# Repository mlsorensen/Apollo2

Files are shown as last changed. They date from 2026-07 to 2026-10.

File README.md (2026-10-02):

# Apollo 2

<picture>
  <source media="(prefers-color-scheme: dark)" srcset="docs/img/apollo-logo-dark.png">
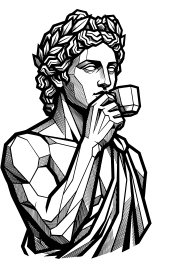
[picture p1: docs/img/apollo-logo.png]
Apollo, laurel-crowned, sipping an espresso
  
</picture>

Firmware project that turns a small ESP32 touchscreen into a local
controller for a **La Marzocco Micra** espresso machine — over Bluetooth, with
no cloud dependency for day‑to‑day use.

Set your brew temperature, flip the steam boiler, put the machine on standby,
watch the boiler come up to temperature, and (with a supported Bluetooth scale)
run a live shot timer and flow graph — all from a dedicated little screen next
to the machine instead of a phone app.

<p align="center">
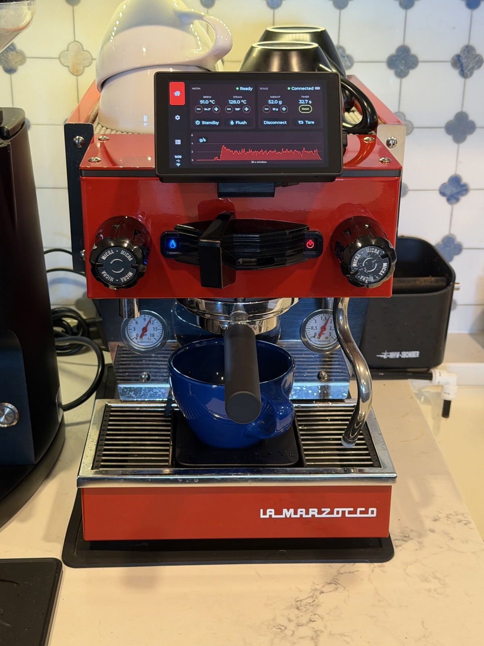
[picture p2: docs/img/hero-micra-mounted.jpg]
Apollo 2 magnet-mounted on a red Micra, Ferrari theme, just after a shot
  
</p>

> The focus is on local control via bluetooth. Currently internet is only used for optional NTP.

**Contents:**
[Features](#features) ·
[Getting started](#getting-started) ·
[Screenshots](#screenshots) ·
[Supported hardware](#supported-hardware) ·
[3D prints](#3d-prints) ·
[Developer documentation](#developer-documentation) ·
[Credits](#credits) ·
[License](#license)

---

## Features

- **Local Micra control over Bluetooth** — brew and steam temperatures, steam
  boiler on/off, standby, and live machine status. No cloud, no phone app.
- **Bluetooth scales** — Bookoo Themis, Acaia (Umbra, Lunar, Prochef, Pyxis)
  and Varia Aku: live weight, shot timer, flow graph, tare, and the scale's
  own settings from the screen.
- **Brew by weight** — stop the shot at a target weight on boards wired into
  the paddle circuit, or detect shots from the weight stream alone on any
  board. Finished shots freeze into a review graph.
- **Group care** — auto‑flush after the cup lifts, flush on demand, and a
  backflush cleaning cycle, on wired boards.
- **Warm‑up chime** — boards with a speaker play a tune when the machine is
  ready, so you can start it and walk away.
- **Schedule** — switch the machine on (with a warm‑up lead) and back to
  standby at set times, the same every day or per weekday, from the device's
  own NTP clock. **Auto‑standby** sends it to standby a set time after the
  last shot, independent of the schedule.
- **Shot history** — every shot is saved to a microSD card as CSV, browsable on
  the device's Stats tab or from a phone via the device's own web page.
- **Settings backup** — preferences copy to the same card and restore onto
  replacement hardware.
- **Over‑the‑air updates** — the device checks for new firmware and installs
  it on request, with an optional beta channel.
- **Setup from your phone, no app** — pairing and Wi‑Fi credentials go in
  through a page the device serves itself; scan the QR code on its screen.
- **Automatic time** — NTP over your Wi‑Fi with a timezone picker, saved to
  the on‑board RTC where present.
- **Made to live on the counter** — themes, °C/°F, 12/24‑hour clock,
  brightness, idle‑screen artwork; layouts from 4.3" to 8" panels.

Everything keeps working if the machine, the scale, or Wi‑Fi is absent — the
UI just shows that part as offline.

---

## Getting started

> [!IMPORTANT]
> **Before buying any hardware, confirm you can get your machine's Bluetooth
> token.** Apollo authenticates to the Micra with a token issued by the La
> Marzocco cloud. Grab it first with the **[LM Token](tools/lmtoken/)** app — sign
> in with your La Marzocco account and copy the token. If it comes back blank, the
> same tool can provision one over Bluetooth. Checking now avoids a nasty surprise
> after a board is already on your bench.

### 1. Get the hardware

Pick a board from the **[Which board?](#which-board)** table below — three of
them come as finished boxes that need no assembly at all. A Bluetooth scale is
optional but unlocks the shot timer, flow graph, and brew‑by‑weight. Wiring
the machine's paddle (for Auto shot) is optional too, and can always be added
later — see the [wiring guide](docs/WIRING.md) (which also covers the
optional Apollo Link board — **P4 boards only**, not the S3‑4.3C).

### 2. Flash the firmware

**No-toolchain option:** the [web flasher](https://mlsorensen.github.io/Apollo2/)
flashes any supported board straight from Chrome, Edge, or Firefox over USB —
pick your board, click Install. (The P4‑5 and P4‑4.3 exist with two ESP32‑P4
chip revisions that need different images; boards bought before about August
2026 are v1.x, newer ones v3. **Detect board** reads it off a device already
running Apollo; on a blank board pick it on the card. A wrong pick just won't
boot until the other image is flashed.) Upgrading this way keeps your paired machine,
Wi‑Fi and settings (unless you choose "Erase device"). Prebuilt images also live
on the [Releases](https://github.com/mlsorensen/Apollo2/releases) page — those
are full images, so flashing one with `esptool` *does* clear saved settings.

Until a Micra is paired, the device opens on a welcome screen with the three
recommended steps: **Set up WiFi** (network and time zone from your phone;
sets the clock and enables updates), **Pair Micra**, and **Pair scale**. All
are optional — **Later** skips it until the next power‑up, **Don't show
again** for good; every step is in Settings too.

After the first flash Apollo updates itself over WiFi: it checks for new
firmware, shows what changed, and installs on a tap. Tick **Include
pre-releases** on the flasher (or turn on **Settings → Apollo → WiFi → Beta
updates** on the device) to run beta builds instead — testing welcome, and a
build that won't boot rolls back on its own.

Building from source requires [PlatformIO](https://platformio.org/) (`pio`) and
a USB cable.

```sh
make flash            # print selection of flash options
make flash-p4-5       # or target a board: p4-5 | p4-4-3 | s3-4-3c | p4-x-8
                      # (P4-5 / P4-4.3 come with two chip revisions needing different
                      #  images; these targets read the chip and pick the right one)
make monitor          # open the serial console (115200 baud)
```

### 3. Pair the machine

**Settings → Micra → Bluetooth → Scan**, then pick your machine. The device saves
it, then asks for the machine's **Bluetooth token** (step 4) — the token is issued
by the La Marzocco cloud and can't be read off the machine, so there's a short
one‑time step to fetch it.

### 4. Enter your token

Tap **Enter token** on the prompt (or **Settings → Micra → Set up**) to start the
device's own Wi‑Fi access point, **`Micra-Setup`**. Scan the QR code on the
device's screen with your phone's camera — it joins the access point and the
setup page pops up on its own. (Or join `Micra-Setup` manually and open
**http://192.168.4.1**.) Paste your token and Save — the device connects and the
access point closes on its own.

Where to get the token:

- Download the **LM Token** app for your OS from the [Releases](../../releases)
  page, unzip, and double-click it. Sign in with your La Marzocco account, pick
  your machine, and hit **Copy token**. This is the only step that uses the
  internet, and it runs on your computer. (Prefer a terminal? The `lmtoken` CLI
  is on the same page.)

> Prefer to build **LM Token** / `lmtoken` from source (Go), or script it? See
> [`tools/lmtoken/README.md`](tools/lmtoken/README.md).

### 5. (Optional) Wi‑Fi + automatic time

On the same setup page you can enter your home Wi‑Fi name and password. The
device then joins your network, gets an IP, and syncs the clock over NTP. Pick
your city under **Settings → Apollo → WiFi → Timezone**. Auto‑sync can be turned
off there too (**Auto time (NTP)**).

Because the setup page is always reachable from **Set up WiFi**, you can never be
locked out if your network changes.

### 6. Find your way around

- **Home** shows the machine (and scale, if paired). The large action button is
  Standby / Turn On when connected, and becomes a **Connect** button when the
  machine is disconnected. With a scale, the pill under the shot timer cycles
  the shot mode — **Auto shot** (wired paddle boards) / **Shot detect** /
  **Manual** — and becomes **Reset** while a finished shot is up for review.
- **Settings** groups everything under Micra, Scale, and Device (brightness,
  clock, units, theme, Wi‑Fi).
- **Stats** shows brew/boiler temperature history, the shot **History** log
  (SD‑card boards), and device info.

Every screen and setting is described in the **[user manual](MANUAL.md)** —
it opens with a **map of every screen and setting** if you're looking for
where something lives.

---

## Screenshots

<p align="center">
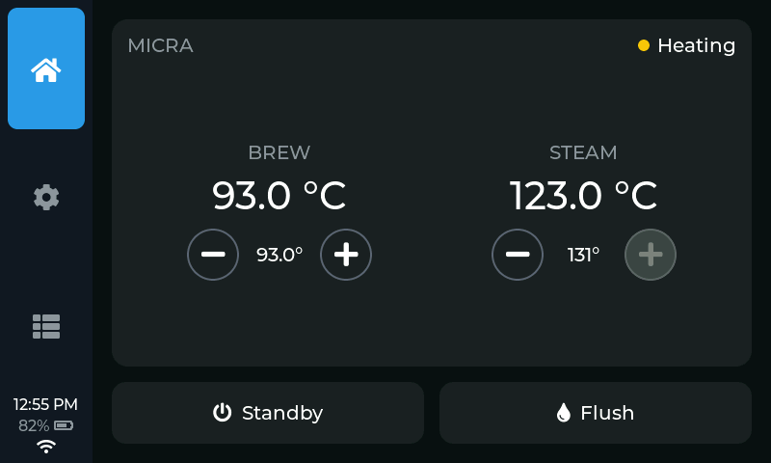
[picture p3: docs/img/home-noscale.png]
Home without a scale — brew/steam hero card
  
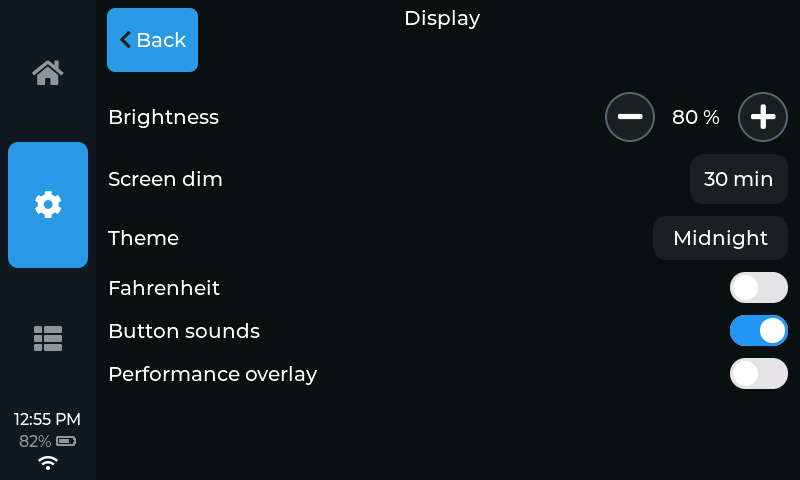
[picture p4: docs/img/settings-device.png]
Device display settings — brightness, theme, units
  
</p>
<p align="center">
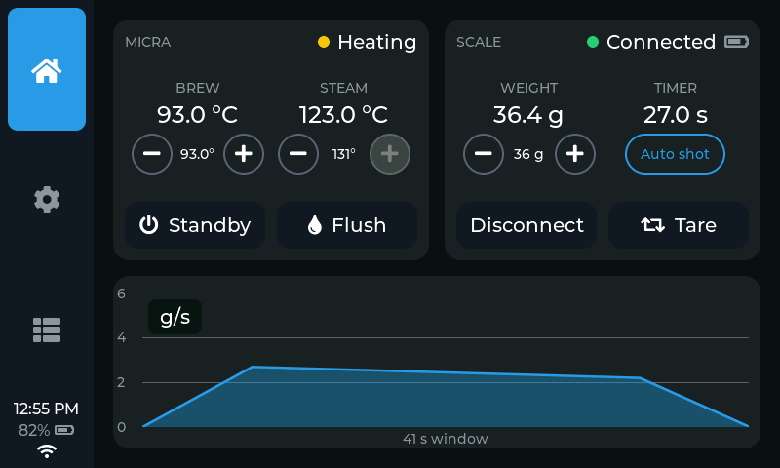
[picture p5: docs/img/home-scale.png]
Home with a paired scale — weight, timer, flow graph
  
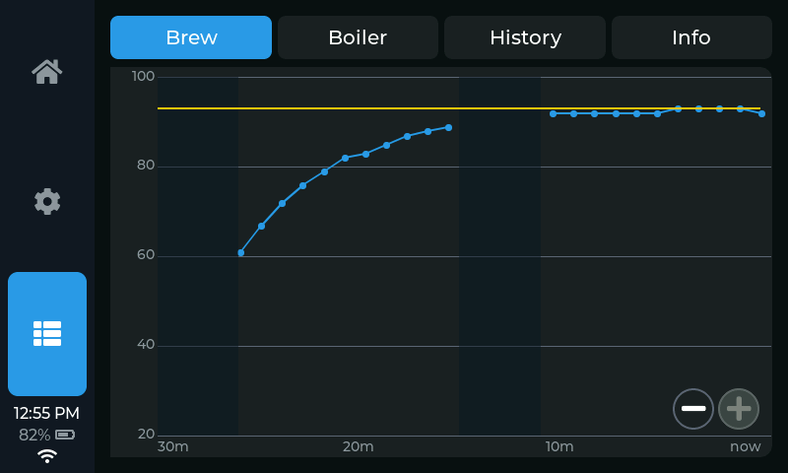
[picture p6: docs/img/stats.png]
Temperature history
  
</p>

<!-- These are curated copies of the simulator's output — see "The simulator"
     under Developer documentation for the refresh convention. -->

---

## Supported hardware

The firmware targets Waveshare ESP32 touch boards. One board is selected at
build time.

### Which board?

Four boards are supported, and each has its own firmware image. Every one of
them delivers the full brew‑by‑weight experience with **zero wiring** (via Shot
detect); the wiring column only matters if you *also* want **Auto shot** — the
wired‑paddle mode where the machine's own paddle starts the shot and the
firmware cuts it at target weight.

| Pick | Best for | Screen | Enclosure | Auto‑shot wiring *(optional)* | Performance |
|---|---|---|---|---|---|
| [ESP32‑P4‑WIFI6‑Touch‑LCD‑5](https://www.waveshare.com/esp32-p4-wifi6-touch-lcd-5.htm) (SKU 33762) | **Mounting on the Micra** | 5" 1280×720 | [3D‑printed shell](hardware/3d-prints/) | DIY cable with an external opto module | **Best** |
| [ESP32‑P4‑WIFI6‑Touch‑LCD‑4.3](https://www.waveshare.com/esp32-p4-wifi6-touch-lcd-4.3.htm) | **Mounting on the Micra, smaller screen** | 4.3" 800×480 | [3D‑printed shell](hardware/3d-prints/) | DIY cable with an external opto module | **Best** |
| [ESP32‑S3‑Touch‑LCD‑4.3C **BOX**](https://www.waveshare.com/esp32-s3-touch-lcd-4.3c.htm?sku=33630) (SKU 33630) | **Mounting on the Micra with nothing to build** | 4.3" 800×480 | Finished box | **Built‑in opto** — three wires into screw terminals, nothing to build (the optional Apollo Link board is P4‑only and does not fit this box) | Good |
| [ESP32‑P4‑WIFI6‑Touch‑LCD‑X **8" box**](https://www.waveshare.com/esp32-p4-wifi6-touch-lcd-7-8-10.1.htm) | **Counter‑top companion** | 8" 1280×800 | Finished box | DIY cable with an external opto module | **Best** |

**Start with the ESP32‑P4‑WIFI6‑Touch‑LCD‑5.** It's the recommended
mount‑on‑the‑Micra option: the P4 is much faster than the S3 (32 MB flash +
32 MB PSRAM against 16/8), and the 5" panel is the right size on the machine.
The cost is two bits of DIY — you print a [shell](hardware/3d-prints/), and if
you want Auto shot you make up a cable with an external opto module.

**The ESP32‑P4‑WIFI6‑Touch‑LCD‑4.3 is the same board with a smaller screen.**
Identical electronics — same processor, radio, audio, battery path, SD slot and
paddle wiring; only the panel differs (4.3" 800×480 instead of 5" 1280×720).
Pick between the two on **screen size and a small price difference**, nothing
else. It takes its own [printed shell](hardware/3d-prints/) and its own
firmware image.

**Choose the S3‑4.3C BOX if you'd rather not print a case or build a cable.** It's the
only small board that arrives as a finished box *and* has the opto‑isolators
built in, so Auto shot is three wires into screw terminals with no cable to
assemble — genuinely the least‑hacking route to a fully wired setup. The
trade is speed: it's the slower part. (The [wiring guide](docs/WIRING.md)
covers both styles.)

**The X 8" box is the counter‑top companion** — the same P4 electronics behind
the biggest screen, in a finished enclosure, for sitting beside the machine
rather than on it. Verified on hardware.

Power, battery and RTC notes live in
**[docs/HARDWARE.md](docs/HARDWARE.md)**.

### 3D‑printed stand, shells and mounts

Ready‑to‑print 3MF files live in [`hardware/3d-prints/`](hardware/3d-prints/):

| File | What it is |
|---|---|
| [`apollo2-stand.3mf`](hardware/3d-prints/apollo2-stand.3mf) | Counter‑top **stand**. Mounts the S3‑4.3C‑BOX directly (it has the matching holes), and every shell below mounts to it the same way. |
| [`apollo2-magnet-mount.3mf`](hardware/3d-prints/apollo2-magnet-mount.3mf) | Optional **magnet mount** — attaches the device to the Micra's top corner instead of the counter. |
| [`apollo2-wiring-gasket.3mf`](hardware/3d-prints/apollo2-wiring-gasket.3mf) | Optional **wiring gasket** — spaces the Micra's cover so the wiring can run underneath it. |
| [`esp32-p4-5-shell.3mf`](hardware/3d-prints/esp32-p4-5-shell.3mf) | Shell for the **ESP32‑P4‑WIFI6‑Touch‑LCD‑5**. |
| [`esp32-p4-5-shell-slim.3mf`](hardware/3d-prints/esp32-p4-5-shell-slim.3mf) | Slimmer shell for the **ESP32‑P4‑WIFI6‑Touch‑LCD‑5** — no battery compartment (USB‑power only). |
| [`esp32-p4-4.3-shell.3mf`](hardware/3d-prints/esp32-p4-4.3-shell.3mf) | Shell for the **ESP32‑P4‑WIFI6‑Touch‑LCD‑4.3**. |
| [`esp32-p4-x-8-backplate.3mf`](hardware/3d-prints/esp32-p4-x-8-backplate.3mf) | Backplate that adapts the **ESP32‑P4‑WIFI6‑Touch‑LCD‑X 8" box** to the counter‑top stand above. |

This [short video](https://youtube.com/shorts/Ea0IaJ7hjvQ) shows how the
magnet mount and wiring gasket fit together on the machine.

Fasteners:

- **Shells**: 8 × **M2.5×0.45, 5 mm** screws each — 4 fasten the board into
  the shell, 4 fasten the shell cover.
- **Stand mount**: 2 × **M4‑0.7×8 mm** screws — same spec whether you're
  mounting the S3‑4.3C‑BOX or any of the printed shells.
- **Magnet mount**: 8 × **10 mm × 3 mm** neodymium disc magnets.

---

## Developer documentation

### Architecture

The code is layered so the same UI runs on a real board and on a laptop:

```
include/core/        Pure interfaces (ports) + domain types. No LVGL, Arduino,
                     BLE, or SDL — just C++ and structs. e.g. IMachine, IScale,
                     IClock, INetwork, IProvisioner, IBrewController, IShotStore
                     (SD shot history), and the BLE central port (ble::ICentral).

src/core/            Portable protocol logic: the La Marzocco Micra link and
                     the Bookoo scale driver, written only against ble::ICentral
                     — so a new platform (Linux/BlueZ, Pico/btstack) reuses the
                     Bluetooth protocol code unchanged and implements only the
                     transport. Also the device-independent decisions: which
                     event makes which sound (sound.cpp), when a warm-up counts
                     as finished (ready_chime.h).

src/ui/              The LVGL user interface. Depends ONLY on core/ interfaces,
                     never on a concrete platform. Portable.

src/platform_esp32/  Device implementations of the core ports: the NimBLE GATT
                     transport, NVS config, display/touch drivers, Wi-Fi
                     station + NTP, the setup-portal web server.

src/platform_host/   "Fake" implementations that feed canned data, so the UI can
                     be built and rendered on a host with no hardware.

src/device/main.cpp  Device entry: wires the real implementations to ui::App.
src/sim/main.cpp     Simulator entry: wires the fakes, renders frames to PNG.
```

The UI is written against the `core::` ports and is injected with concrete
implementations at startup (`App::build(...)`). Swapping the real BLE machine for
a `FakeMachine` is all that separates a board build from a laptop render — the UI
code is byte‑for‑byte identical.

### The simulator

No hardware needed. Builds a native executable that renders each screen/layout
to `renders/*.png`:

```sh
make sim              # build + run, writes renders/*.png
```

This is the fastest way to iterate on UI: change code, `make sim`, look at the
PNGs. Every supported screen size and several states are rendered.

The `renders/` folder is git‑ignored build output; the screenshots in
`docs/img/` are curated copies, and the annotated manual images in
`docs/img/manual/` are generated from renders by `make docs-img`
(`tools/annotate_docs.py` + its manifest). **When the UI changes, run
`make sim`, refresh the affected `docs/img/*.png`, and re-run `make docs-img`
as part of the same change** so the README and manual stay accurate.

### Prerequisites

**PlatformIO** (`pip install platformio`) builds everything, and **node** (any
recent LTS — `brew install node`) builds the shot-history web page the device
serves. That page is embedded in the firmware as a generated header,
`include/platform_esp32/webapp_dist.h`, which is **not committed**: every
`make build`/`make flash` target rebuilds it when anything under
[`tools/webapp/`](tools/webapp) changes, and the release workflow does the same,
so a board can never serve a page that has drifted from the source. `make sim`
needs no node — the simulator has no web server.

### Building directly

`pio run` does *not* generate the web-app header (that dependency lives in the
Makefile), so run `make webapp` first — or just use the `make` targets, which
handle it.

```sh
pio run -e esp32-p4-micra-5       # 5"   1280x720 (P4, MIPI-DSI, WiFi6/BLE via C6)
pio run -e esp32-p4-micra-43      # 4.3"  800x480 (P4, MIPI-DSI, same board as the 5)
pio run -e esp32-p4-micra-5-rev3  # the same two boards on the v3 ESP32-P4 silicon
pio run -e esp32-p4-micra-43-rev3 #   (shipping since ~Aug 2026; a separate image)
pio run -e esp32-s3-micra-4-3c    # 4.3"  800x480 (S3, RGB panel)
pio run -e esp32-p4-micra-x-8     # X-series 8" box (P4, 1280x800)
pio run -e sim                    # native simulator
```

`platformio.ini` also carries a few envs for boards that aren't released — they
build, and they're kept as the record of how those boards differ. `make
build-release` compiles the three published images; `make build-all` compiles
every env.

Build environments and per‑board flags live in
[`platformio.ini`](platformio.ini); the pin/panel definitions for each board are
in [`include/platform_esp32/board_config.h`](include/platform_esp32/board_config.h).

### Adding a board

Add an `#elif defined(BOARD_...)` block in `board_config.h` with the same
constant names the drivers read (pins, panel size, feature macros), then add a
matching `[env:...]` in `platformio.ini` with the `-DBOARD_...` flag. Driver code
never hardcodes a pin — it reads `board::` constants — so a new board is mostly a
config block.

That makes the board *buildable*, not *supported*. Releasing one is a separate,
deliberate step: a row in the `.github/workflows/firmware-release.yml` matrix
(whose `board` value must equal the block's `kUpdateSlug`, since the
self‑updater fetches `<site>/<tag>/firmware/app/<slug>.bin`), a card in
`site/index.html`, and a row in the tables above. (The flasher's engine,
esp-web-tools, is vendored by `tools/build_esp_web_tools.sh` with a pinned
esptool-js rather than loaded from unpkg — the script says why.) Releases are
tagged `vX.Y.Z`;
a `vX.Y.Z-beta.N` tag publishes the same images as a pre-release, listed only in
`releases-beta.json` (the stable `releases.json` every device reads stays
releases-only) — promoting one to stable is a rebuild at the real tag, never a
copy of the artifacts, because `fw::kVersion` is compiled into the image.
Publishing is gated: the workflow builds unattended, but the jobs that create
the Release and push `gh-pages` (the OTA origin) run in a protected
environment that holds the only write credential and waits for the owner's
approval, and repository rulesets let only an admin touch `gh-pages` or a
`v*` tag. Several envs stay on the
buildable side on purpose.

### Repository layout

```
include/core/          Domain interfaces + types
src/core/              Portable protocol implementations (Micra BLE, scales,
                       audio cues)
include/platform_esp32/ Device driver headers + board_config.h
include/platform_host/  Host fakes
include/ui/             UI headers (widgets, screen profiles, timezones)
include/vendor/         Vendored third-party headers (stb_image_write)
src/                    Implementations (see Architecture above)
hardware/3d-prints/     Printable stand, board shells + mounts (3MF)
tools/                  sim.sh, flash.sh, lmtoken (Go), PlatformIO helper scripts
renders/                Simulator output (PNG)
```

---

## Credits & third‑party

This project stands on the work of others. Grateful thanks to:

- **[pylamarzocco](https://github.com/zweckj/pylamarzocco)** by Josef Zweck
  (MIT) — the reference for La Marzocco's Bluetooth protocol (GATT
  characteristic UUIDs, the JSON command/state payloads, machine name prefix) and
  the cloud auth flow that `tools/lmtoken` re‑implements in Go.
- **[goscale](https://github.com/mlsorensen/goscale)** (Apache‑2.0) — the model
  for the scale interface and the Bookoo Themis notification decode.
- **[apollo](https://github.com/mlsorensen/apollo)** — brew‑by‑weight /
  paddle‑stop approach that inspires the (in‑progress) brew controller.
- **Waveshare** — board bring‑up details and register maps for the CH422G IO
  expander, GT911 / CST816 touch controllers, and the RGB panel timings, from
  their published ESP32‑S3 demos.
- **[stb_image_write](https://github.com/nothings/stb)** by Sean Barrett (public
  domain / MIT) — vendored in `include/vendor/` for PNG output in the simulator;
  its license is retained in the file.

Library dependencies (fetched by PlatformIO): **LVGL** (MIT), **NimBLE‑Arduino**
(Apache‑2.0), **Arduino‑ESP32** (LGPL‑2.1 / Apache‑2.0), **GFX Library for
Arduino** (BSD‑style), and **ArduinoJson** (MIT). Each retains its own license.

---

## License

[MIT](LICENSE) © 2026 Marcus.

Not affiliated with or endorsed by La Marzocco. "La Marzocco" and "Micra" are
trademarks of their respective owner; used here only to describe compatibility.

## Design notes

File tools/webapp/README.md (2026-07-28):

# Apollo 2 web app

The shot-history page the device serves at `http://<device-ip>/` — a
single-file React + Material UI app, gzipped and embedded in the firmware
as `include/platform_esp32/webapp_dist.h`.

It styles itself from the DEVICE'S ACTIVE THEME at load (`/api/summary`
carries the palette), so the page always matches the screen.

## Building

You don't, normally: the embedded header is a **generated build artifact, not
committed**, and every device target depends on it —

    make build      # or make flash, make build-p4-5, ...

rebuilds it whenever anything in this directory changes, and the release
workflow does the same. That's what keeps the page a board serves from drifting
from the source here. To build it on its own:

    make webapp     # == tools/webapp/build.sh

**This makes node a dev dependency of any device build** (`brew install node`;
any recent LTS). `make sim` doesn't need it — the simulator has no web server.
If you invoke `pio run -e <env>` directly instead of going through `make`,
build the header first or the firmware won't compile.

`node_modules/`, `dist/` and the generated header are all git-ignored.

## Development

    npm install
    npm run dev     # vite dev server on localhost

The dev server has no device behind it, so `/api/*` calls fail — proxy them to a
real board in `vite.config.js` when working on data-driven parts.

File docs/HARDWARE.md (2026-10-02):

# Supported hardware

The four boards the firmware is built and published for, in detail. The
short version — and the buying advice — lives in the README's
[Which board?](../README.md#which-board) table.

## Supported boards

| Board | Best for | Display | Wired paddle (Auto shot) | Notes |
|---|---|---|---|---|
| **ESP32‑P4‑WIFI6‑Touch‑LCD‑5** | Mounting on the Micra | 5" 1280×720, MIPI‑DSI (HX8394) | **Yes — external opto.** Native GPIOs (51/52 on the 40‑pin header) + a PC817‑style opto module you wire | **The default pick.** ESP32‑P4, 32 MB flash / 32 MB PSRAM, WiFi 6 + BLE via an on‑board ESP32‑C6. UI scaled 1.5×. Speaker, microSD, battery monitoring. No enclosure — printable shells are [in the repo](../hardware/3d-prints/). |
| **ESP32‑P4‑WIFI6‑Touch‑LCD‑4.3** | Mounting on the Micra, smaller screen | 4.3" 800×480, MIPI‑DSI (ST7701) | **Yes — external opto.** Same wiring as the P4‑5 | **The same board as the LCD‑5** — identical processor, radio, audio, battery path, SD slot and paddle pins; only the panel differs. Choose between them on screen size and a small price difference. UI at 1:1 (800×480). Its own printed shell, its own firmware image. |
| **ESP32‑S3‑Touch‑LCD‑4.3C / 4.3C‑BOX** | Mounting on the Micra with nothing to build | 4.3" 800×480, RGB parallel | **Yes — built‑in.** Not compatible with the optional Apollo Link board (P4 only). Isolated DI/DO screw terminals (opto‑isolators on board), so there is no cable to assemble | **The no‑DIY pick:** the only supported board that is both a finished box *and* pre‑isolated. Slower than the P4s (ESP32‑S3R8, 16 MB flash / 8 MB octal PSRAM). Dimmable backlight, battery monitoring, PCF85063 RTC, speaker, microSD. |
| **ESP32‑P4‑WIFI6‑Touch‑LCD‑X 8"** | Counter‑top companion | 8" 1280×800, MIPI‑DSI (JD9365) | **Yes — external opto.** Same wiring as the P4‑5 | Finished box, biggest screen, same P4 electronics as the LCD‑5. UI scaled 1.6×. Verified on hardware (v3 silicon). |

**Two ESP32‑P4 chip revisions.** The P4‑5 and P4‑4.3 have shipped with two
generations of ESP32‑P4 silicon under the same product name: rev v1.x
(engineering‑sample silicon, sold in volume until about August 2026, 360 MHz)
and rev v3.x (production silicon since then, 400 MHz). The two are
binary‑incompatible, so each has its own firmware image (`…-rev3` for v3),
and the device updates itself along the right line once flashed. There is no
user‑visible difference in Apollo. The [web flasher](https://mlsorensen.github.io/Apollo2/)
reads the revision off a board already running Apollo; on a blank board pick it
on the card (`esptool chip-id` tells you: "revision v1.3" or "v3.2"). The X 8"
has only ever shipped with v3 silicon.

Auto‑shot wiring is optional on every board: without it you still get the full
brew‑by‑weight experience via **Shot detect**, and only the automatic stop at
target weight needs the wire. Step‑by‑step wiring instructions (with photos of
the Micra's paddle loom) are in the **[wiring guide](WIRING.md)**. P4 boards
also have an optional open‑hardware alternative, the
[Apollo Link](WIRING.md#apollo-link-optional-p4-boards) board: the paddle
keeps working with Apollo off, and one cable carries the paddle *and* powers
the display. **P4 boards only — the S3‑4.3C cannot use it** (it has its own
isolators and no header for the Link).

A supported Bluetooth scale (Bookoo Themis, Acaia Umbra / Lunar / Prochef /
Pyxis, or Varia Aku — Pyxis and Aku untested) is optional but unlocks the shot
timer, flow graph, and brew‑by‑weight features.

## Power, battery, and RTC

The boards run from **USB‑C power** — that's the normal way to use them. An
optional battery can be installed (the boards have a battery connector), but
it only lasts a few hours, so treat it as a nice‑to‑have for moving the device
around, not a way to run it. An optional **RTC coin cell** (on the 4.3C,
which has one) keeps the clock through a power‑off — but it's only
needed if you *don't* configure Wi‑Fi + NTP, which sets the time automatically
on every boot.

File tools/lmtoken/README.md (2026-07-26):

# lmtoken

Logs into your La Marzocco cloud account and fetches a machine's **BLE auth
token** (the `bleAuthToken` used for local Bluetooth control). Two frontends
share the same Go implementation — no `pylamarzocco`, no Python runtime:

- **LM Token** (`cmd/lmtoken-gui`) — a small [Fyne](https://fyne.io) desktop
  app: double-click, sign in, pick your machine, hit **Copy token**. No
  terminal needed.
- **lmtoken** (`cmd/lmtoken`) — the original dependency-free CLI, unchanged
  behavior, still ideal for scripting.

The cloud protocol lives in the root `lmtoken` package (standard library
only); the Fyne dependency is confined to the GUI binary.

## GUI app

```sh
make build          # builds bin/lmtoken and bin/lmtoken-gui for this machine
make package-gui    # clickable app for THIS OS (macOS: "LM Token.app" → dist/)
```

Fyne renders with OpenGL through CGO, so the GUI is built **per-OS** (each OS
packages its own; a C toolchain is required — Xcode CLT on macOS, gcc + X11/GL
dev headers on Linux, MinGW on Windows). To cross-package Linux/Windows apps
from one machine use [fyne-cross](https://github.com/fyne-io/fyne-cross)
(needs Docker): `make package-gui-cross`.

macOS signing: `package-gui` ad-hoc signs the bundle by default (without
*any* bundle signature Gatekeeper reports downloaded copies as "damaged" —
the Go linker only signs the binary). Releases go one step further:
`make release-mac TAG=lmtoken-vX.Y.Z` rebuilds both arches signed with a
Developer ID (`CODESIGN_ID`), notarizes them (`notarytool`, keychain
profile `lmtoken`), staples, and replaces the darwin zips + checksums on
the GitHub release — so downloads open with no Gatekeeper prompt at all.

Sign in with your La Marzocco account email + password; if the account has
several machines you'll get a picker. The token screen shows the token with a
**Copy token** button — paste it into the remote's setup page
(`Micra-Setup` Wi-Fi → http://192.168.4.1). The app remembers your email (not
your password) for next time.

## CLI

```sh
go build -o lmtoken ./cmd/lmtoken
```

Cross-compile for any platform (no C toolchain needed):

```sh
GOOS=darwin  GOARCH=arm64 go build -o lmtoken-macos-arm64 ./cmd/lmtoken
GOOS=linux   GOARCH=amd64 go build -o lmtoken-linux-amd64 ./cmd/lmtoken
GOOS=windows GOARCH=amd64 go build -o lmtoken.exe ./cmd/lmtoken
```

or `make build-all` / `make package` for the full release matrix. Ship the
resulting file as-is; it has no runtime dependencies.

### Usage

```sh
./lmtoken
```

Prompts for your account email and password (password input is hidden), then:

- if the account has **one** device, prints its BLE token;
- if it has **several**, lists them and asks you to pick one.

The token is the only thing written to **stdout** — prompts and the device list
go to **stderr** — so you can capture it directly:

```sh
TOKEN=$(./lmtoken)
```

### Non-interactive

```sh
export LAMARZOCCO_USERNAME='you@example.com'
export LAMARZOCCO_PASSWORD='…'
./lmtoken -serial MR000000      # pick a device by serial, no prompt
```

Flags / env:

| Input | Purpose |
| --- | --- |
| `-u <email>` | account email (else `$LAMARZOCCO_USERNAME`/prompt) |
| `$LAMARZOCCO_USERNAME`  | account email |
| `$LAMARZOCCO_PASSWORD`  | account password (else hidden prompt) |
| `-serial <serial>` | select a device by serial, skipping the picker |

## How it works

Each run mints a fresh installation key (P-256), registers it with the cloud
(`/auth/init`), signs in (`/auth/signin`), and lists devices (`/things`). All
requests carry La Marzocco's custom byte-rotation "proof" plus an ECDSA-signed
header. Because the installation key is fresh every run, it never collides with
a previously registered one (the cause of the intermittent HTTP 400s when an id
is reused).

The proof algorithm and key derivation are cross-checked byte-for-byte against
the reference Python implementation in `token_test.go` (`go test`).

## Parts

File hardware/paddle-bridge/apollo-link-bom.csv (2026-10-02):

Ref | Qty | Value | Package | Description | Manufacturer | MPN | Notes
U2 U3 | 2 | LH1502BB | DIP-8 THT | Dual 1-Form-A/B solid-state relay, used as SPDT (350 V, 150 mA); 8/7 = NC to Micra, 6/5 = NO to remote | Vishay | LH1502BB | THT on purpose: Panasonic AQW612EH drops in if the NC/NO mapping proves wrong (then R2-R5 -> 270R). Meter 8-7 continuity unpowered before fab.
U1 | 1 | AQY212EH | DIP-4 THT | 1-Form-A PhotoMOS relay (60 V, 550 mA, 3 mA max LED); drives Micra W/B from GPIO52 | Panasonic | AQY212EH | AQY212EHA is the SMD variant - board wants the DIP.
J1 | 1 | JST PH 5-pin side-entry | THT | JST PH 2.0 mm 5-pos side-entry header; Apollo (GND_R/5V/DRIVE/SENSE/CTRL) | JST | S5B-PH-K-S(LF)(SN) | Same drills as vertical B5B-PH-K if side-entry is out of stock.
J2 | 1 | JST PH 4-pin side-entry | THT | JST PH 2.0 mm 4-pos side-entry header; machine (P1/P2/W/B) | JST | S4B-PH-K-S(LF)(SN) | Same drills as vertical B4B-PH-K if side-entry is out of stock.
J3 | 1 | USB-C receptacle | THT | USB 2.0 Type-C receptacle, through-hole; 5 V power in only (VBUS -> J1 5V, GND -> GND_R) | GCT | USB4085-GF-A | Power only: D+/D-/SBU unused. R9/R10 (5k1 Rd on CC1/CC2) make it a default-5 V sink so any USB-C source | PD or not | turns VBUS on.
R1 R2 R3 R4 R5 | 5 | 330R | 1206 | Thick film resistor 330 ohm 1% 0.25 W; R1 = U1 LED, R2-R5 = U2/U3 LEDs | Panasonic | ERJ-S08F3300V | Switch to 270R if AQW612EH is fitted.
R6 | 1 | 1k | 1206 | Thick film resistor 1 kohm 1% 0.25 W; SENSE series protection | Panasonic | ERJ-S08F1001V
R7 | 1 | 10k | 1206 | Thick film resistor 10 kohm 1% 0.25 W; SENSE pull-up (with D1) | Panasonic | ERJ-S08F1002V
R8 | 1 | 2k2 | 1206 | Thick film resistor 2.2 kohm 1% 0.25 W; LED1 current limit | Panasonic | ERJ-S08F2201V
D1 | 1 | 1N4148W | 1206 land (SOD-123 part) | Small-signal diode; pull-up steering for R7 | Diodes Inc | 1N4148W-7-F | PCB pads are D_1206; 1N4148W is SOD-123 and sits on them - check fit or pick a 1206-bodied diode.
LED1 | 1 | green | 1206 | Green indicator LED, lit while CTRL is high | Lite-On | LTST-C150KGKT | Suggestion only - any 1206 green LED.
R9 R10 | 2 | 5k1 | 1206 | Thick film resistor 5.1 kohm 1% 0.25 W; USB-C CC1/CC2 Rd pull-downs to GND_R | Panasonic | ERJ-S08F5101V | One per CC pin - never share one resistor between CC1 and CC2.
F1 | 1 | 1.5A PTC | 1812 | PTC resettable fuse, 1.5 A hold / 3.0 A trip, 12 V, 1812; in series with USB-C VBUS before J1 5V | Littelfuse | 1812L150/12DR | Bourns MF-MSMF150-2 is EOL. Alternate: TE MINISMDC150F-2 (6 V, same pads). Hold current derates roughly 1%/degC above 25 C (about 0.9 A at 85 C). Measured load: 0.6 A battery-less, 1.0 A with a battery charging (X-8, 2026-10-02) - fine at room temperature, but a charging unit in a hot spot approaches the derated hold; consider 2 A (e.g. 1812L200) if that case matters.

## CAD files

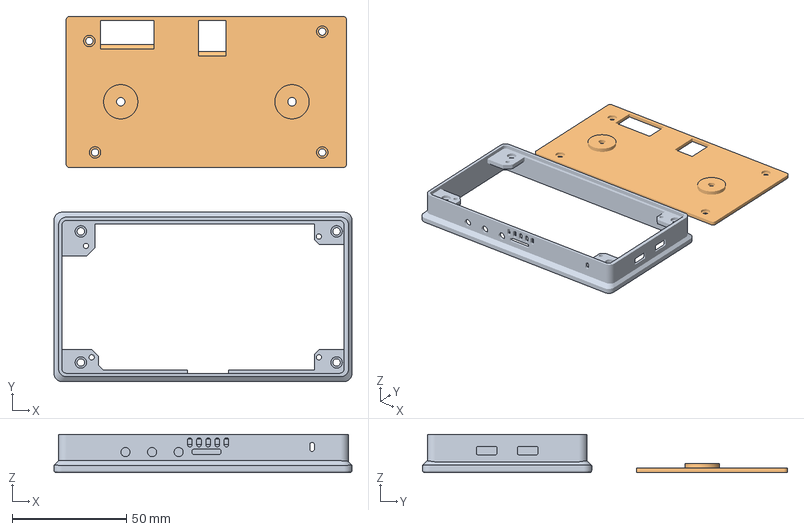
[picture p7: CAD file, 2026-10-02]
hardware/3d-prints/esp32-p4-5-shell-slim.3mf
130.5 x 160.0 x 16.8 mm

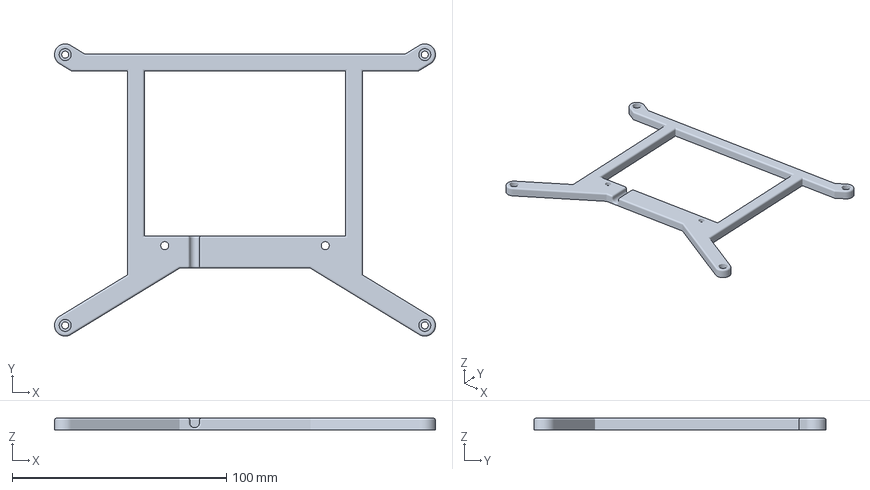
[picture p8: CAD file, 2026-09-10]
hardware/3d-prints/esp32-p4-x-8-backplate.3mf
178.0 x 136.5 x 5.50 mm

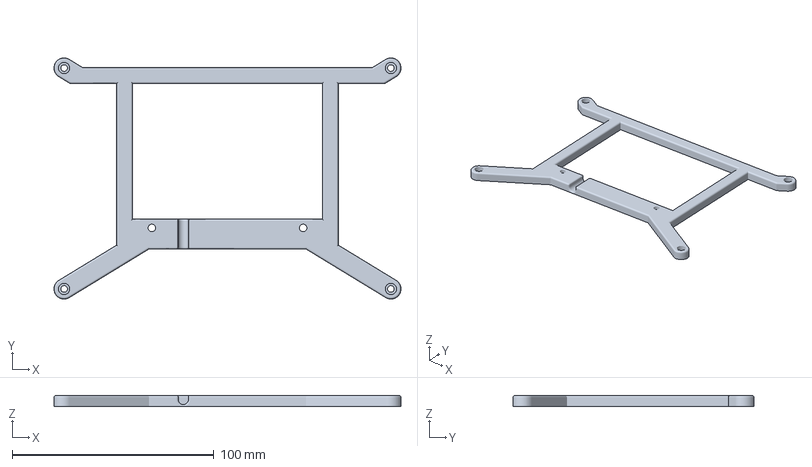
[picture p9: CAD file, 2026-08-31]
hardware/3d-prints/esp32-p4-x-7-backplate.3mf
172.0 x 119.5 x 5.50 mm

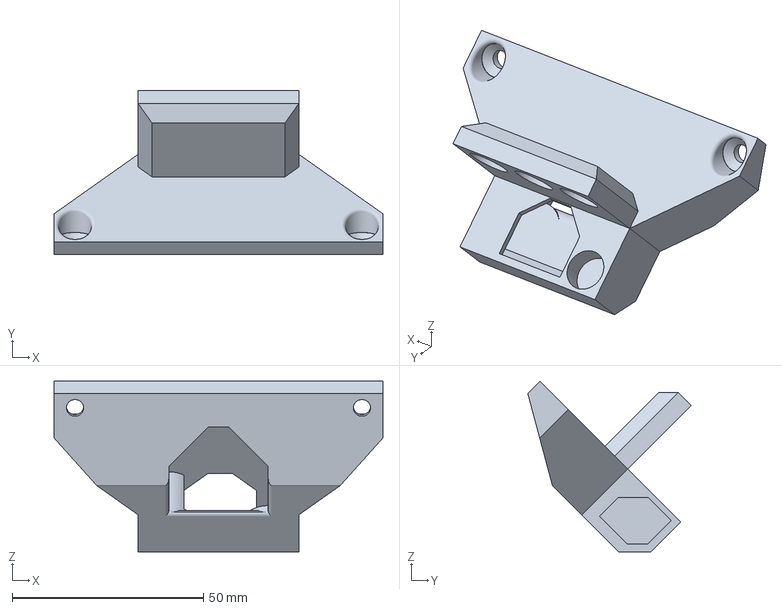
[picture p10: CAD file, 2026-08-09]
hardware/3d-prints/apollo2-magnet-mount.3mf
86.0 x 42.7 x 44.6 mm

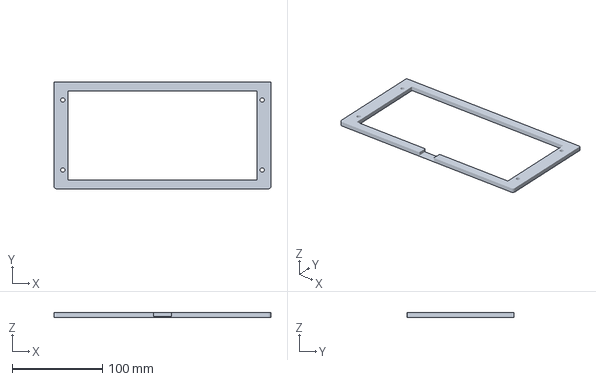
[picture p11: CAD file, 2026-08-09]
hardware/3d-prints/apollo2-wiring-gasket.3mf
240.0 x 118.0 x 5.00 mm

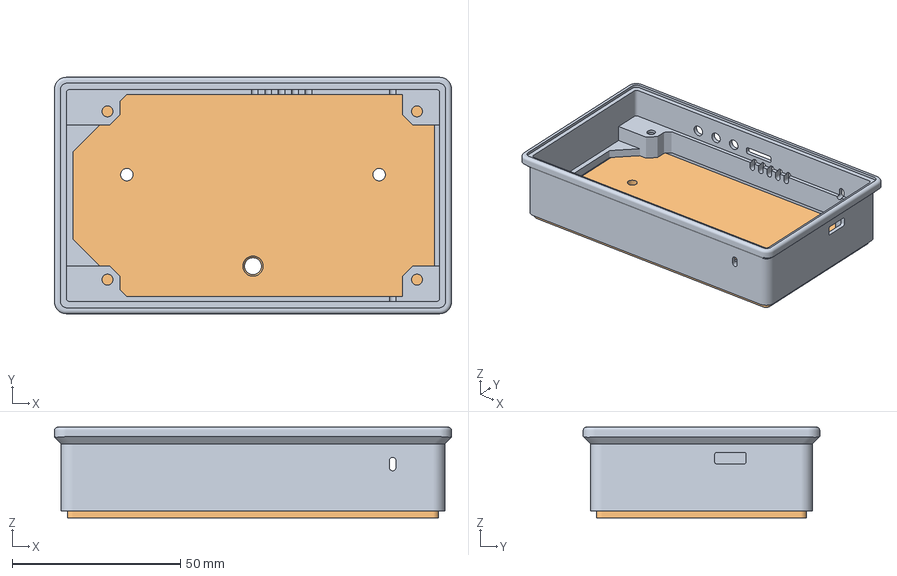
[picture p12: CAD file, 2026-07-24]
hardware/3d-prints/esp32-p4-4.3-shell.3mf
118.0 x 70.3 x 27.0 mm
back_plate

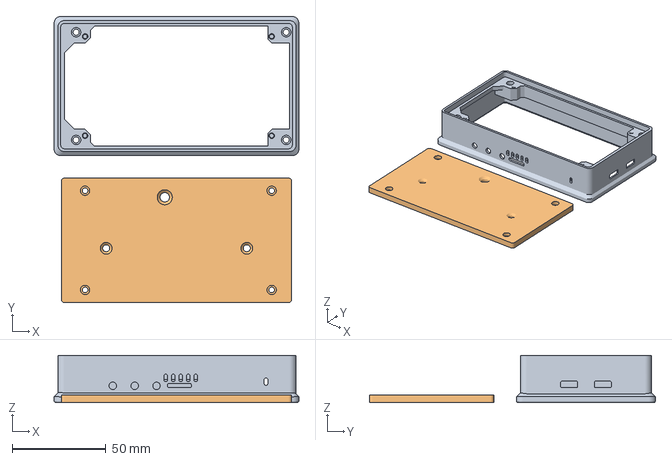
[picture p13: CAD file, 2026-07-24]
hardware/3d-prints/esp32-p4-5-shell.3mf
130.5 x 152.5 x 25.2 mm
back_plate

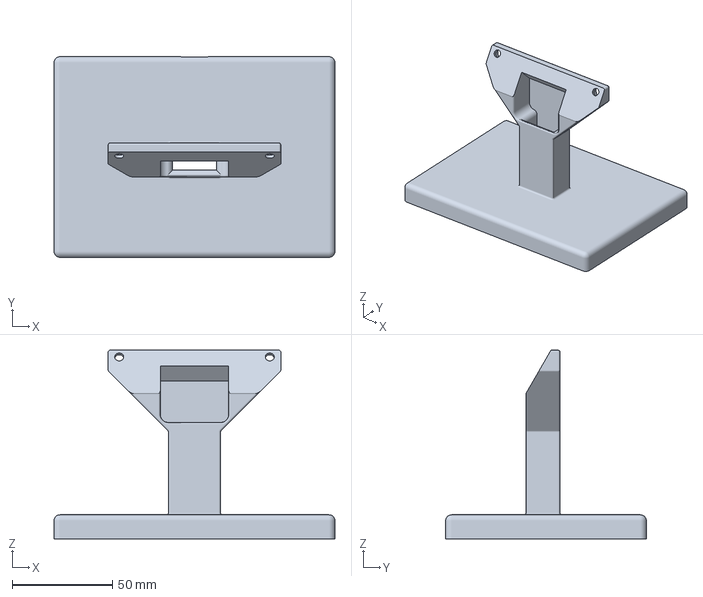
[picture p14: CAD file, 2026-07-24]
hardware/3d-prints/apollo2-stand.3mf
140.0 x 100.0 x 94.0 mm

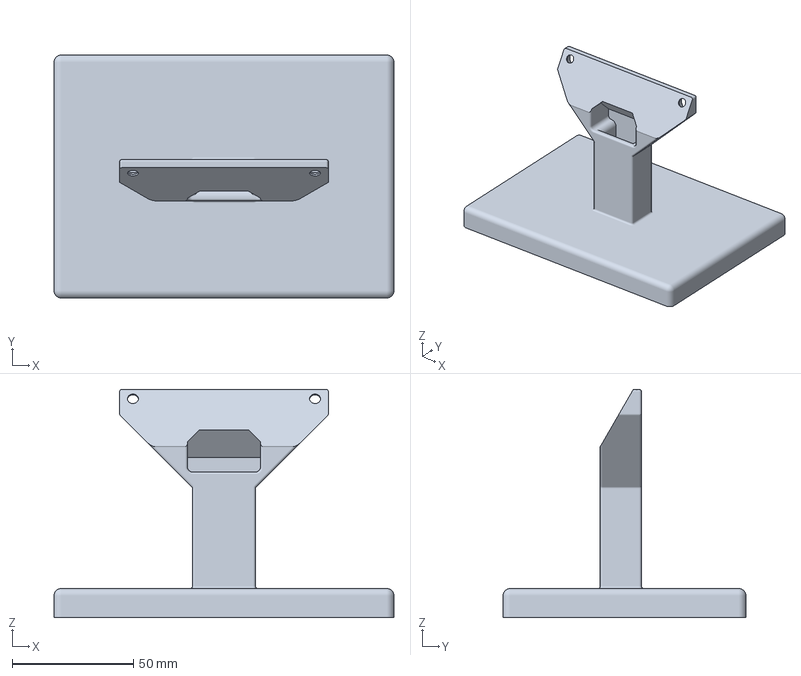
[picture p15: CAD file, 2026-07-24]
hardware/3d-prints/esp32-s3-4.3c-shell.3mf
140.0 x 100.0 x 94.0 mm

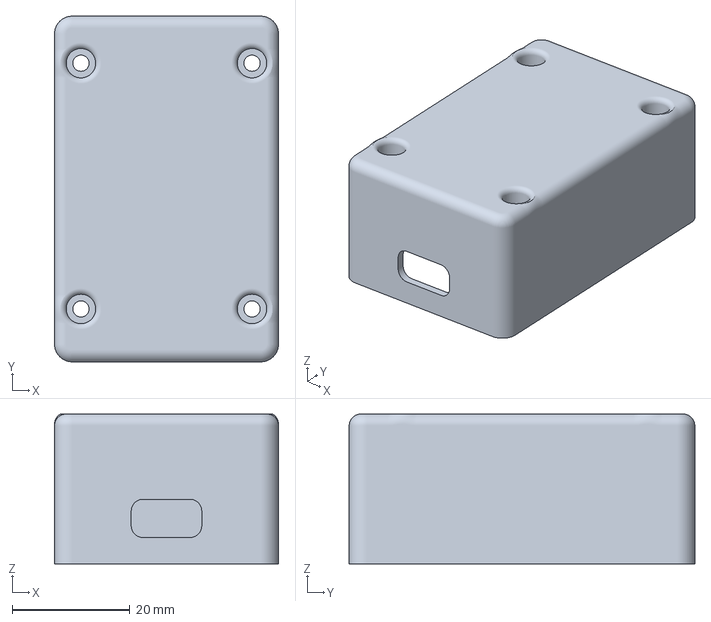
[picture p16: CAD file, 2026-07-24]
hardware/3d-prints/esp32-s3-2-shell.3mf
38.1 x 58.8 x 25.5 mm

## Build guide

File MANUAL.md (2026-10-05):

# Apollo 2 user manual

Everything the firmware can do, screen by screen and setting by setting. For
flashing and first‑time pairing, start with the [README](README.md#getting-started).

Some rows only appear where the hardware supports them — a switch you don't see
(for example **Wired paddle** on a board without paddle wiring, or
**Brightness** on a board whose backlight can't dim) simply doesn't apply to
your board.

**Contents:**

- [Where everything lives](#nav-map) — a map of every screen and setting
- [Home](#home) — MICRA card · SCALE card · Flow graph · Shot lifecycle
- [Settings → Micra](#settings-micra) — Bluetooth · Controls · Cleaning · Schedule
- [Settings → Scale](#settings-scale) — Bluetooth · Shot settings · Device
  settings · Per‑scale nuances
- [Settings → Apollo](#settings-device) — Display · Time & date · WiFi ·
  Backup · Root page
- [Stats](#stats-section) — Brew/Boiler graphs · History · Info
- [Brew‑by‑weight quick reference](#bbw-reference)

---

## Where everything lives

<!-- Keep this map in sync with the UI: when a setting/page is added, moved,
     or renamed, update the tree below (and the prose sections). -->

Every screen and setting, and how to reach it:

```
Home
├─ MICRA card — status · BREW/STEAM temps + set-point steppers
│  ├─ [Power]  Standby / Turn On / Connect
│  └─ [Flush]  quick group rinse                *(wired-paddle boards)*
├─ SCALE card — status · WEIGHT (+ target) · TIMER   *(scale paired)*
│  ├─ [shot-mode pill]  Auto shot → Shot detect → Manual  (Reset in review)
│  └─ [Connect/Disconnect] · [Tare]
└─ Flow graph — g/s ↔ g toggle · freezes for review after a shot

Settings
├─ Micra
│  ├─ Bluetooth — Scan · saved machine (Setup / Connect / Forget) · Auto connect
│  ├─ Controls  — Wired paddle* · Chime melody* · Chime volume*
│  │             · Brew Temperature · Steam Enable + Temperature
│  ├─ Cleaning* — Auto flush · Flush delay · Backflush cleaning  → cleaning mode
│  └─ Schedule  — Auto-standby after last shot · Show auto-standby timer
│                · Enable schedules · Same every day · Smart Warm-up
│                └─ Configure schedule — day chips · Day enabled · On at / Off at
│                                        · range slider · Copy times to
├─ Scale
│  ├─ Bluetooth       — Scan · saved scale (Connect / Forget)
│  ├─ Shot settings   — Target · Review hold · Detect lead-in · Smoothing
│  │                    · Drop negative g/s · Oscilloscope graph · Window growth
│  └─ Device settings — Battery display (Icon / Percent / Icon + %)
│                       · the scale's own settings (Beep · Auto-off/sleep · Unit …)
├─ Apollo
│  ├─ Display     — Brightness* · Screen timeout · Idle screen (Lion/Apollo/Alternate/Dim/Off)
│  │               · Theme · Fahrenheit · Button sounds* · Performance overlay
│  ├─ Time & date — Time · Date · 24-hour · Timezone
│  ├─ WiFi        — Enable · Status · Set up WiFi → QR portal (network, time zone,
│  │                 DHCP / static address) · Forget
│  │               · Auto time (NTP) · Check for updates (Off/Boot/Daily/Hourly)
│  │                 → notice → Install now · Beta updates
│  └─ Backup      — On the card · Back up to card · Restore from card
└─ Lock display for cleaning  → 30 s touch lock

Stats
├─ Brew | Boiler — temperature history graphs (+/− zoom)
├─ History — headline stats (tap → reset) · month filter · shot list
│            └─ tap a shot → full-screen shot card (with delete)
└─ Info — firmware (→ Check for updates) · uptime · IP (DHCP/static) · NTP synced · Diagnostic log
          (tap → viewer) · Micra details

  * = only on boards whose hardware supports it (see the note above)
```

---

## Home

**First boot.** Until a Micra is paired, the device opens on a welcome screen
listing the three recommended steps, each with a button: **Set up WiFi**
(starts the phone setup page, where you enter the network and, optionally,
your time zone — that sets the clock over NTP and enables updates and the
schedule), **Pair Micra** (Settings → Micra → Bluetooth; have your token
ready) and **Pair scale** (Settings → Scale → Bluetooth). A step already done
drops its button. Every step is optional — skip one and Apollo still works,
just without what it brings. **Later** closes the screen until the next
power‑up, so a power cycle mid‑setup loses nothing; **Don't show again** stops
it for good, and pairing the Micra stops it on its own.

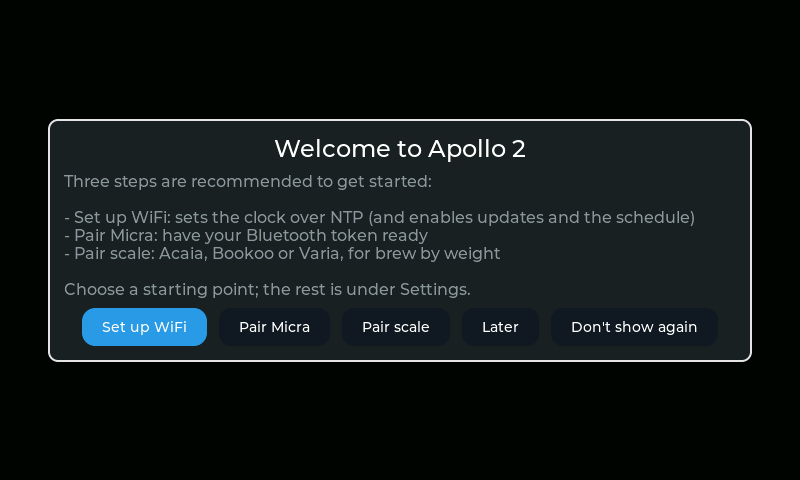
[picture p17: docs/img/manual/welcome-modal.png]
The first-boot welcome
  

The Home screen adapts to the screen size and to whether a scale is paired.
Without a scale, the MICRA card fills the screen as a single hero:

Home without a scale

### MICRA card

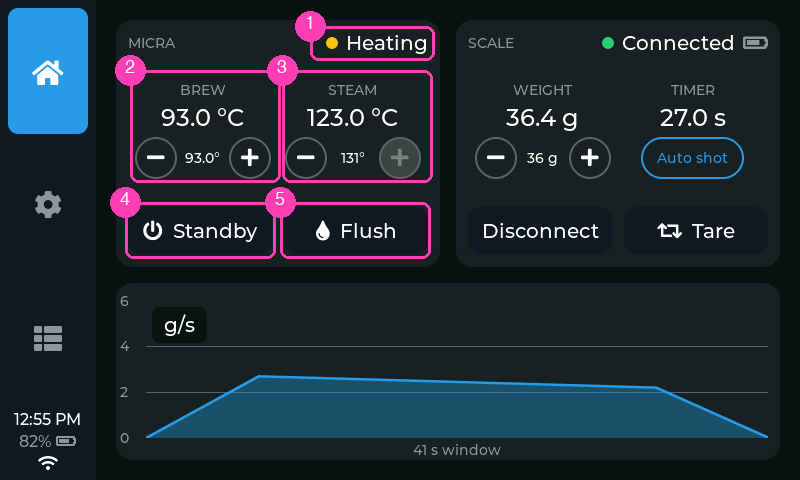
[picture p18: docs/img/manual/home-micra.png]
MICRA card


- ① **Status** — `Not set up` (no machine chosen yet), `Setup unfinished`
  (a machine is chosen but pairing never completed — in both of these the Power
  button reads **Pair Micra** and takes you straight to Settings > Micra >
  Bluetooth), `Disconnected`, `Connecting...`, `Heating` (powered on, boilers still coming
  up to temperature — the dot pulses amber), `Ready` (at temperature), or
  `Standby`. The Micra itself doesn't report a warm‑up state; `Heating` is
  inferred from the live boiler temperatures vs their set‑points. A boiler
  within **2 °C** of its set‑point counts as ready, because the machine's own
  thermostat works to about that tolerance — a steam boiler set to 128 °C
  routinely settles at 127 °C and stops heating there. Boards with a speaker
  can also chime when it turns `Ready` — see
  [Settings → Micra → Controls](#controls).
  While **Auto‑standby** is counting down (and *Show auto‑standby timer* is
  on), the header also shows the minutes left next to the caption:

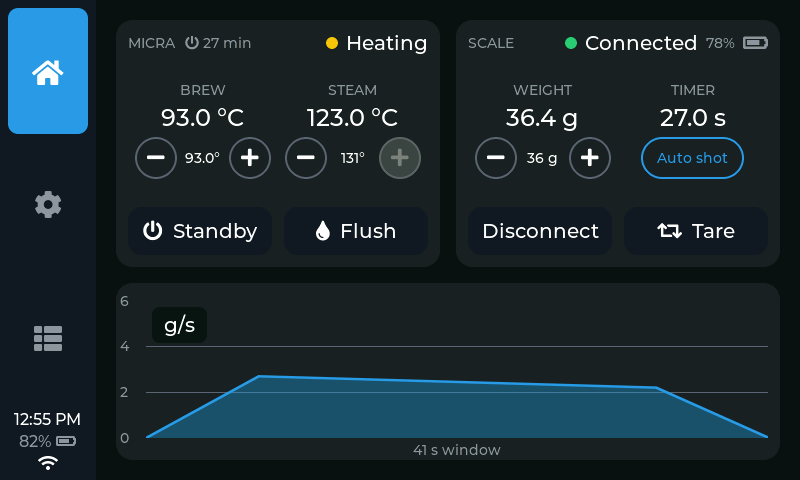
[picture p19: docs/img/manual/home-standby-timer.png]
Auto-standby countdown on the MICRA card
  

- ② ③ **BREW / STEAM** — live boiler temperatures. On larger screens each has a
  **−/+** stepper that edits the set‑point directly; the small grey number is
  the current target. Edits are written to the machine as you tap.
- ④ **Power button** — `Standby` / `Turn on` when connected. After a tap it
  briefly reads `Working...` (disabled) until the machine reports the change —
  the Micra's answer trails the command by a couple of seconds, and the button
  would otherwise look like it did nothing (a command sent by the
  [Schedule](#schedule) shows the same). When the machine is configured but
  disconnected it becomes **Connect** and starts the Bluetooth link.
- ⑤ **Flush** *(paddle‑wired boards, screens 4.3" and larger)* — runs the group
  for a quick rinse, for the same time as **Auto flush** (3 s when Auto flush
  is Off). Tap again while it runs to stop early; it also reads **Stop** while
  an auto flush is running, and stops that. Greyed out while a shot is in
  flight or the machine is in standby.

### SCALE card (when a scale is paired)

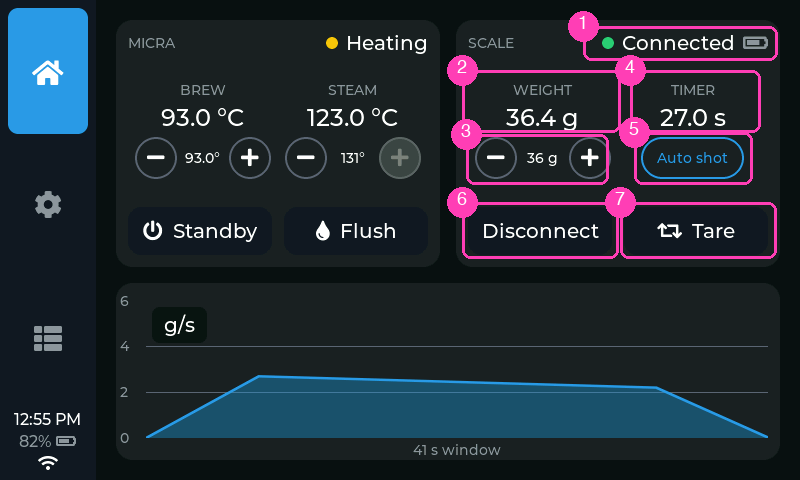
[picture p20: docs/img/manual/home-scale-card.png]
SCALE card


- ① **Status** — `Connected`, `Connecting...`, or `Sleeping` (sleep‑capable
  scales such as the Acaia Umbra with the link switched off). A small battery
  icon shows the scale's own battery where the scale reports it.
- ② **WEIGHT** — live reading. During a finished shot's review it freezes at the
  net shot weight so lifting the cup doesn't wipe the number you care about.
- ③ **TARGET** — the brew‑by‑weight stop target in grams (**−/+** on larger
  screens; also under **Settings → Scale → Shot settings → Target**).
- ④ **TIMER** — the shot timer. Runs from the ESP's own clock whenever the
  firmware is the shot authority (Auto shot or Shot detect, and every wired
  shot); in Manual mode without a wire it falls back to the scale's built‑in
  timer.
- ⑤ **Shot mode pill** (under the timer) — tap to cycle the shot mode:
  - **Auto shot** *(only with a wired paddle — see below)*: flipping the
    Micra's paddle starts the shot (auto‑tare, timer, graph), and the firmware
    opens the paddle circuit by itself when the weight reaches
    *target − overshoot*. The overshoot compensation is learned from each
    auto‑stopped shot's settled weight, so accuracy improves over the first
    few shots.
  - **Shot detect** *(needs a paired scale — with none paired the firmware
    runs in Manual mode whatever was last chosen, and the pill isn't shown)*:
    no wiring needed — the shot is detected from the weight
    stream alone (start when flow sustains, stop when flow ceases). There is
    no auto‑stop; instead the pill flashes **Stop** when the shot reaches the
    point where the auto‑stop would have fired, telling you to flip the
    paddle now. Detection confirms a few seconds after the first drip; the
    moment it does, the timer, weight and graph snap to the full shot —
    back‑dated to the estimated start, including the **Detect lead‑in**
    (see **Settings → Scale → Shot settings**).
  - **Manual**: nothing armed. A wired board still relays the paddle and times
    the shot; otherwise the scale's own timer is shown.
  - While a finished shot is frozen for review the pill reads **Reset** —
    tap it to dismiss the review and return to live monitoring.
  - The pill is disabled while a shot is running or settling.
- ⑦ **Tare** — zeroes the scale. (Tares are sent twice under the hood; some
  scales drop single tare commands.)
- ⑥ **Disconnect / Connect** — drops or re‑establishes the scale link, e.g. to
  save the scale's battery.
- Like the shot‑mode pill, **Tare** and **Disconnect** are disabled while a
  shot is running or settling — either would disturb the weight the stop math
  runs on. They re‑enable the moment the shot is over, however it ends.

### Flow graph

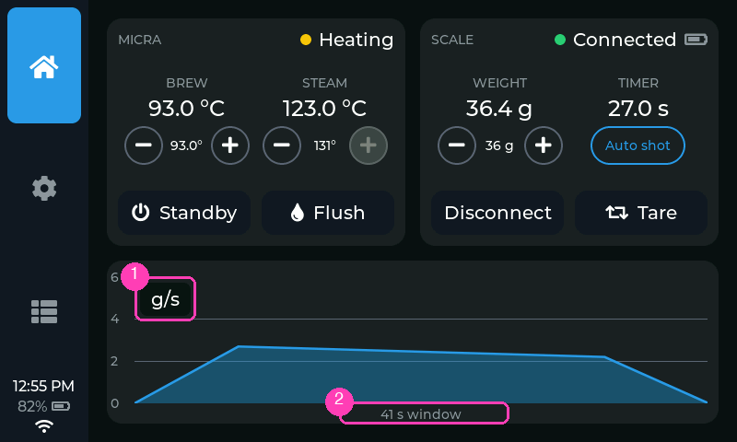
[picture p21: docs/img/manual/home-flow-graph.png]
Flow graph


Plots the live flow rate (or weight) from the scale.

- Tap the **g/s** chip ① to switch between flow rate (g/s) and weight (g);
  the caption ② names the time window in view.
- During a shot the graph restarts and follows the shot, widening its time
  window as the shot runs on (see **Window growth**); when the shot ends it
  freezes for review (see **Review hold**) and then resumes.
- The graph style (oscilloscope sweep vs scrolling) and smoothing are set under
  **Settings → Scale → Shot settings**.

### Shot lifecycle notes (all modes)

- A run shorter than **8 seconds** never becomes a "shot" — it's treated as a
  flush/rinse and discarded silently. Shot detect additionally requires a few
  grams of net gain.
- **Auto shot and Shot detect refuse to start without the scale.** Flipping
  the paddle while the scale isn't connected leaves the machine off and pops a
  message — connect the scale (or wake it) or switch to **Manual** mode. This
  catches the "flipped the paddle, then noticed the scale was never set up"
  shot. Waking a standby machine with a paddle flip still works (no water
  moves), and deliberate untracked runs remain available via Manual mode or
  the **Flush** button.
- On wired boards, flipping the paddle ON **while a review is frozen** is
  swallowed (the machine does not start) and the **Reset** pill flashes —
  dismiss the review first, then start the next shot. This prevents an
  expected auto shot from silently running as a manual one.

---

## Settings → Micra

### Bluetooth (machine)

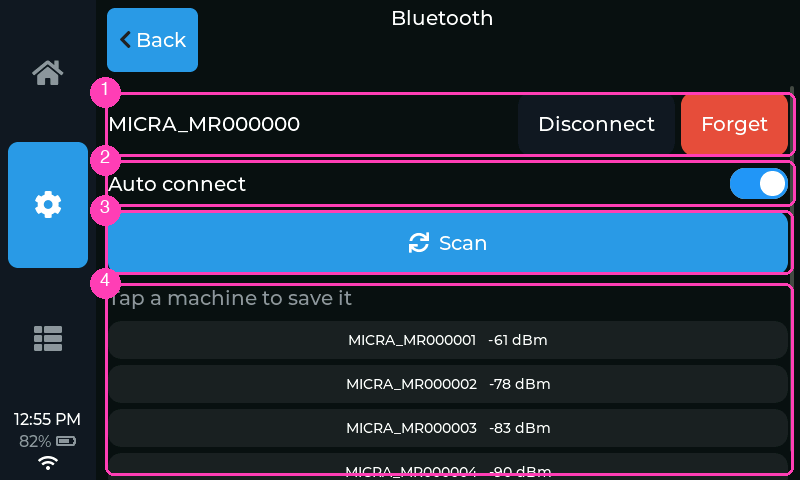
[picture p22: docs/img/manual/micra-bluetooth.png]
Micra Bluetooth


- ③ **Scan** — searches for La Marzocco machines; found machines list below ④,
  tap one to save it. Scanning takes priority over
  in‑progress background connections (a scale stuck in `Connecting...` no
  longer blocks it). If nothing is found the status line says so — make sure
  the machine is powered on and in range, then scan again.
- ① **Saved machine row** — shows the paired machine with:
  - **Setup** (only until a token is stored) — starts the token entry flow
    (see the [README](README.md#4-enter-your-token)):

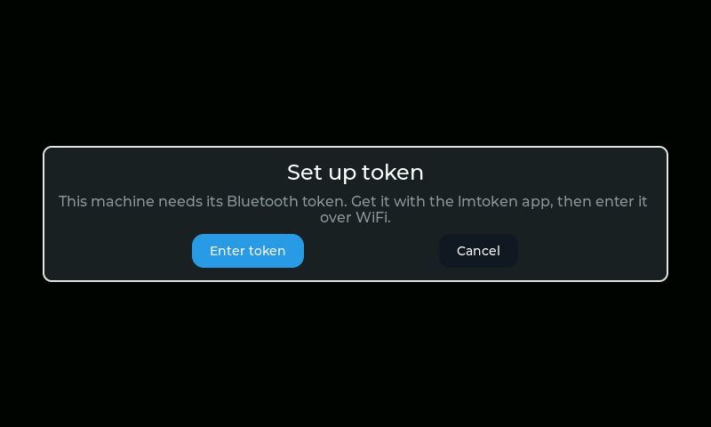
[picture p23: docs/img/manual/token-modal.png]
Token setup prompt
    

  - **Connect / Disconnect** — manual link control. The Micra accepts only one
    Bluetooth client, so Disconnect frees it for another remote or the phone
    app.
  - **Forget** — clears the machine, its name, and its token.
- ② **Auto connect** *(default on)* — connect to the saved machine automatically
  at power‑up. Turn off if another controller needs the Micra's single
  Bluetooth slot.

### Controls

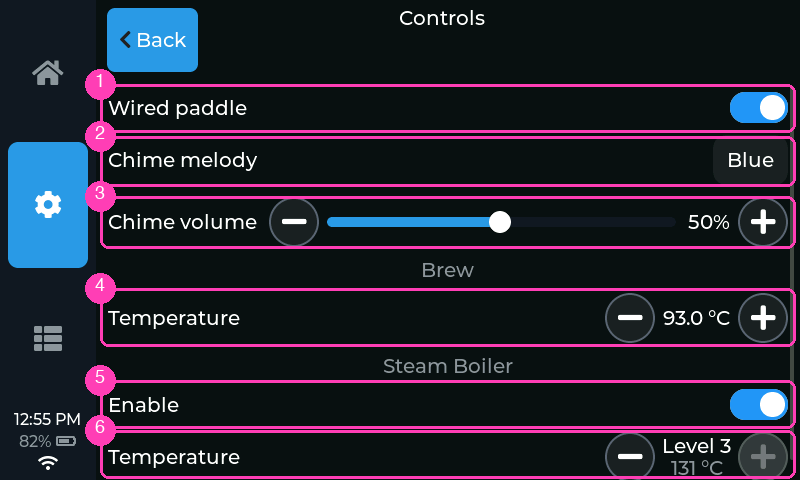
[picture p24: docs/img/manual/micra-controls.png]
Micra Controls


- ① **Wired paddle** *(paddle‑capable boards; default off)* — tell the firmware
  the paddle harness is physically wired. This enables the **Auto shot** mode
  and the auto‑flush. Off, the board behaves like an unwired one (Shot detect
  / Manual only) — the paddle still runs the machine, but without the shot
  timer, Auto shot or cleaning, so the first paddle flip the firmware sees
  with this off pops a one‑time reminder pointing here. Flipping it mid‑shot
  cancels the shot.
- ② **Chime melody** *(boards with a speaker; Off / Blue / Pink / Human /
  Gold / White / Autumn / Random, default Blue)* — which tune announces the end of a warm‑up. Each tap
  cycles to the next melody and auditions it; **Random** picks a different
  tune each time the machine warms up; `Off` silences the chime regardless of
  the volume below.
- ③ **Chime volume** *(boards with a speaker; 0–100 %, default 80 %)* — the
  warm‑up chime's level, so you can walk away and be called back. Drag the
  slider to get close, or tap **–** / **+** to nudge it 5 % at a time; either
  way it **plays a note at the new level** so you can set it by ear. `0 %`
  shows as `Off` and silences it. The scale is even *to the ear* rather than
  arithmetically — each step is the same size in loudness, so the lower half
  is as useful as the upper half.

  The chime marks the *end of a warm‑up*, not every moment the boilers are at
  temperature, so it sounds **at most once per turn‑on** and then stays quiet
  through everything the session brings — the small dips and reheats that hold
  the temperature, heavy steaming, refills, steam boiler toggles. It re‑arms
  only when the machine goes to standby (or off, or disconnects), so the next
  turn‑on's warm‑up chimes again. With the steam boiler **off** the chime
  follows the coffee boiler alone; with it **on**, both boilers have to be
  there.
- ④ **Brew → Temperature** — coffee boiler set‑point stepper (0.1 °C steps;
  long‑press for 0.5 °C).
- ⑤ **Steam Boiler → Enable** — steam boiler on/off.
- ⑥ **Steam Boiler → Temperature** — one of the Micra's three steam levels
  (shown as Level 1–3 with the temperature underneath).

### Cleaning *(paddle‑capable boards)*

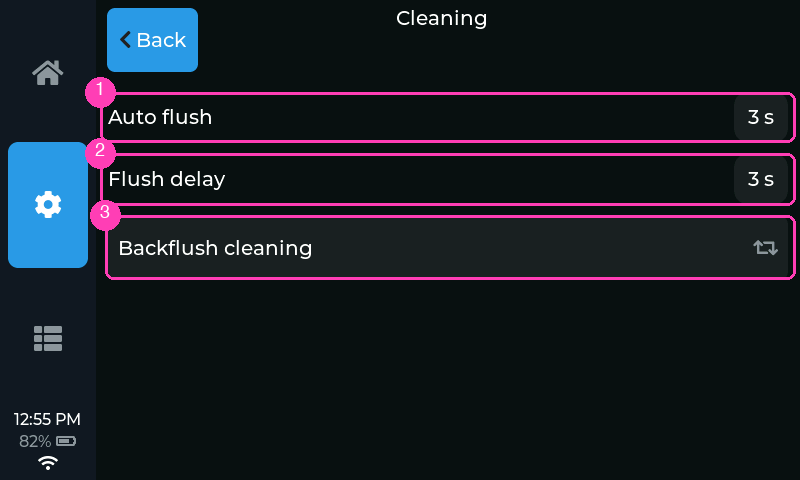
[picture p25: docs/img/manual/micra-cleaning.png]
Micra Cleaning


Everything that deliberately runs water through the group. The whole page
needs the paddle harness, since that's what drives it: with **Wired paddle**
off (Settings → Micra → Controls) every row here is greyed out and a line at
the top says so.

- ① **Auto flush** *(Off / 3 / 6 / 9 / 15 s; default Off)* — after a finished
  shot, when the scale sees the cup lift off, the firmware waits (see **Flush
  delay**) and then runs the group for this long to rinse the puck's surface.
  Before it starts, flipping the paddle on, a new shot, or the machine being in
  standby cancels it. Once it is running the paddle is ignored — flipping it
  back to rest won't cut the rinse short — and the Home **Flush** button reads
  **Stop** to end it early.
  **This one duration drives every timed group run**: the auto‑flush, the Home
  **Flush** button, and each backflush pulse. With Auto flush Off the other two
  fall back to 3 s.
- ② **Flush delay** *(shown while Auto flush is on; 3 / 6 / 9 / 15 s; default
  3 s)* — the pause between the cup coming off and the flush running.
- ③ **Backflush cleaning** — opens a full‑screen cleaning mode. Fit the blind
  filter with detergent, tap **Go**, and the device pulses the group **10
  times: ⟨Auto flush⟩ seconds on, 3 seconds off**, showing the cycle count, a
  countdown, and the total up front. **Cancel** stops the sequence and stays on
  the screen so you can run it again; **Back** stops it and leaves. Flipping
  the physical paddle also stops it — you always outrank the automation. When
  it finishes, rinse the basket and run it again with plain water to clear the
  detergent. Greyed out unless the machine is on and no shot is in flight.
  - **Preinfusion/prebrew matters here.** Each pulse starts a fresh brew, so
    the machine preinfuses *every time*. A pulse shorter than your preinfusion
    never engages the pump, so it runs at line pressure only — water still
    flows and it still rinses, just with far less force than a pump‑pressure
    backflush. If that's not what you want, either raise **Auto flush** until
    the pulse comfortably outlasts preinfusion, or turn preinfusion off while
    you backflush.

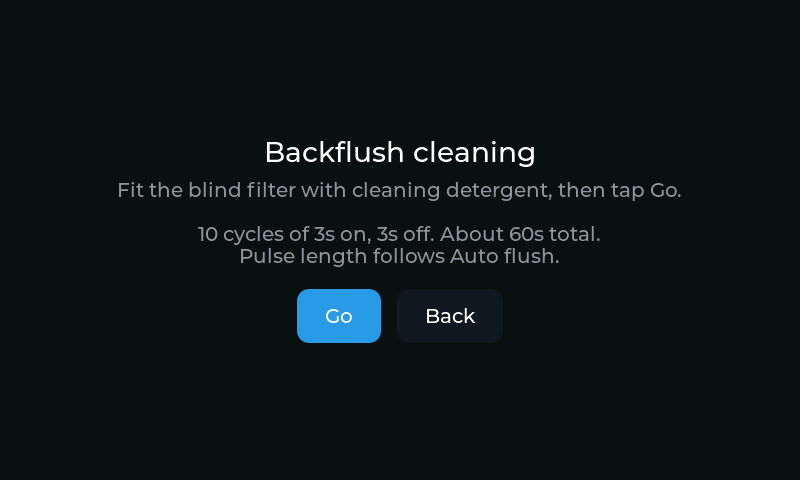
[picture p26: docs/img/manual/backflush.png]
Backflush cleaning mode
  

### Schedule

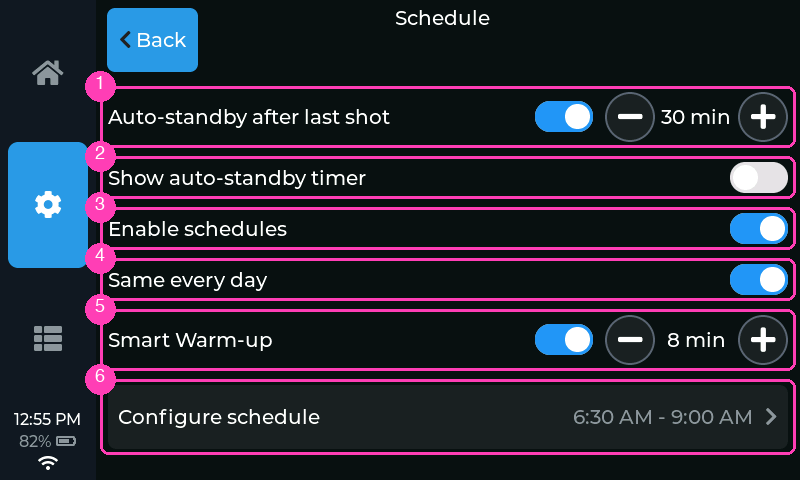
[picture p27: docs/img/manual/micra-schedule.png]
Micra Schedule


Turns the machine on and sends it to standby at set times, from the device's
own clock, so it is warm when you walk up and asleep when you don't. Two
pages, neither of which scrolls: **Schedule** holds Auto‑standby and the
schedule switches, one per line, and **Configure schedule** holds the times.
**The schedule rows are greyed out until two things hold:** a paired Micra,
and a clock the device can trust — WiFi on with **Auto time (NTP)** synced
since the last power‑up (see [Settings → Apollo → WiFi](#wifi)). The page
doesn't say which is missing; if the rows won't take a tap, check those two.
Auto‑standby needs only the paired Micra. The first time you open the page a notice asks you to turn off any
schedule in the La Marzocco app — two schedules for one machine conflict and
confuse. **OK** dismisses it until the next restart; **Don't show again**, for
good.

- ① **Auto‑standby after last shot** *(default off, 30 min; 10–240 in
  10‑minute steps)* — independent of the schedule rows below: sends the
  machine to standby this long after the **last shot**, like the Micra's own
  auto‑standby. Each shot restarts the count; a machine that was switched on
  but never used is left alone, so a scheduled turn‑on stays up until you use
  it (and a scheduled turn‑on cancels a running count). It needs only a
  paired Micra — no WiFi, no clock, and it works with the schedules switched
  off. It does need to *see* shots, though: through a wired paddle, or a
  paired scale in Shot detect mode. With neither, a line under the row says
  so and the count can never start.
- ② **Show auto‑standby timer** *(default off)* — while a count is running,
  the Home MICRA card shows the minutes left next to its caption (see
  [MICRA card](#micra-card)).
- ③ **Enable schedules** *(default off)* — the master switch for the timed on
  and standby. Off keeps the times you set and greys out the rows below it;
  Auto‑standby is not affected.
- ④ **Same every day** *(default on)* — one window for the whole week. Turn it
  off for per‑day times: the Configure schedule page grows a row of day chips
  (below) and each day gets its own On at / Off at. **Turning it off copies
  the daily window onto all seven days** as the starting point, so you only
  edit the days that differ.
- ⑤ **Smart Warm‑up** *(default on, 8 min; 0–30)* — starts the machine this
  many minutes *before* On at, so the boilers are at temperature by the
  scheduled time. One setting for the whole week. A lead that reaches past
  midnight simply starts the evening before.
- ⑥ **Configure schedule** — opens the times page below. The row shows the
  current window at a glance, or *Per day* once the days differ.

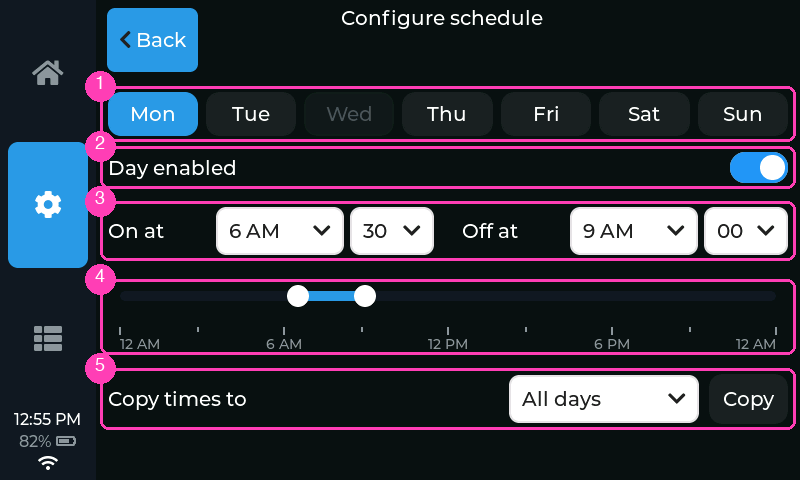
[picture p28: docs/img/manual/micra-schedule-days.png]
Configure schedule, per day
  

- ① **Day chips** *(Same every day off)* — pick which day the rows below edit.
  A day that is switched off reads faded.
- ② **Day enabled** *(Same every day off)* — whether the selected day takes
  part. Off greys the time controls beneath and the schedule skips the day;
  its times are kept.
- ③ **On at / Off at** *(5‑minute steps; default 6:30 → 9:00)* — the window.
  Off is always later than On on the same day (a window never crosses
  midnight); moving one end past the other pushes the other along.
- ④ **Slider** — the same window as a bar across the day, midnight at the
  left edge and 23:55 at the right, with an hour axis underneath (a tick every
  three hours, labelled at 6 AM, noon and 6 PM). Drag either end; the pickers
  follow, and vice versa.
- ⑤ **Copy times to** *(Same every day off)* — copies the shown day's On at /
  Off at onto the picked day, or onto **All days**, without changing which
  days are switched on.

How it behaves:

- **The times are triggers, not a period.** On at switches the machine on
  once; Off at sends it to standby once. Between them do as you like — switch
  it off by hand and it stays off; switch it on early and On at simply finds
  it already on.
- **Auto‑standby counts from the last shot, not from turn‑on.** Turn the
  machine on by hand and pull nothing, and it stays on; pull a shot and the
  count starts, restarting with every shot. If the count runs out mid‑shot
  or during the review, it simply restarts when the shot ends. Standby by
  any route — you, the schedule, this — ends the count, and a machine
  already in standby makes the scheduled Off at a no‑op.
- **Standby waits for the shot.** If Off at lands while a shot is running or
  still under review, standby holds until the device has been idle for about
  two minutes (long enough for the auto‑flush and the cup to come off), then
  goes ahead if the machine is still on.
- **Only while connected.** A trigger fires only if the Micra is connected at
  that minute (a two‑minute window covers hiccups). If the link is down —
  disconnected on purpose, or the machine off at its switch — that trigger is
  skipped, not queued. Likewise nothing fires while WiFi is off, Auto time is
  off, or no Micra is paired; the times you set are kept for when they are
  back.
- The Home **Power** button reads `Working...` while a scheduled command is in
  flight, and a short notice says what the schedule just did (unless the idle
  screen is up). When Smart Warm‑up is what fired, the notice says so — for
  example *Smart Warm‑up: on 8 min before 6:30 AM* — so an early start isn't
  mistaken for a wrong time.

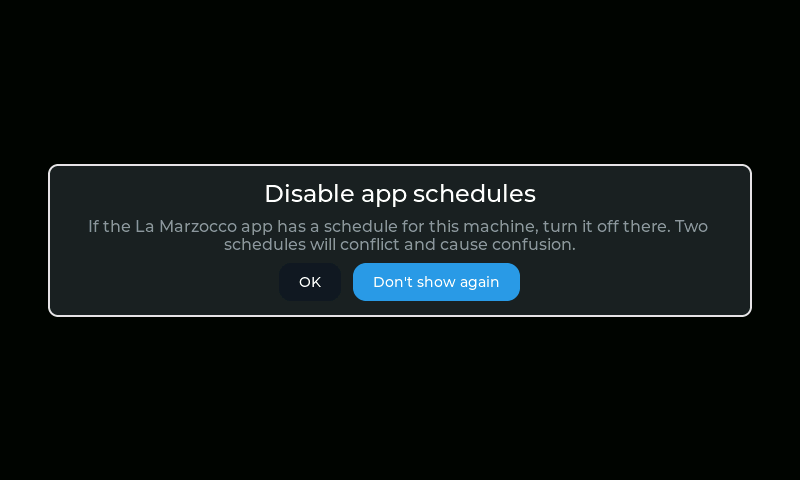
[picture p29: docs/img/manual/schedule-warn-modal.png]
The one-schedule notice
  

---

## Settings → Scale

### Bluetooth (scale)

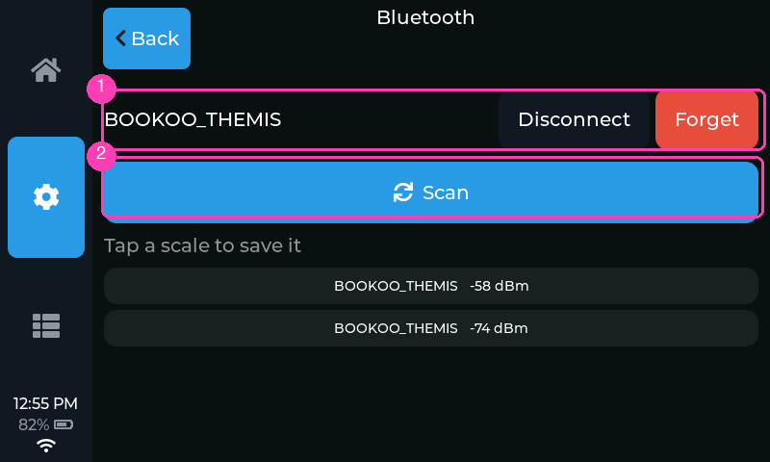
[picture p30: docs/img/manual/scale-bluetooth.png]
Scale Bluetooth


- ② **Scan** — searches for supported scales (Bookoo Themis, Acaia Umbra /
  Lunar / Prochef / Pyxis, Varia Aku — Pyxis and Aku untested). Wake the scale first — most
  sleep their Bluetooth quickly.
- ① **Saved scale row** — **Connect / Disconnect** and **Forget** (no token
  needed for scales).

### Shot settings

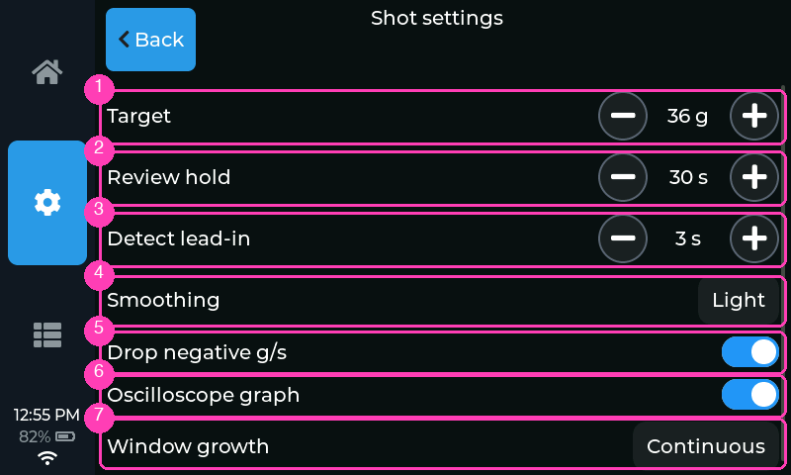
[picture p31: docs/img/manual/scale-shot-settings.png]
Shot settings


- ① **Target** — brew‑by‑weight stop target, 5–120 g. Also editable from Home on
  larger screens.
- ② **Review hold** *(5–120 s, default 30 s)* — how long a finished shot's frozen
  graph and weight linger before auto‑dismissing. **Reset** dismisses early.
- ③ **Detect lead‑in** *(0–10 s, default 3 s)* — Shot detect mode only. The
  detector notices a shot at the first weight rise, but the shot started
  earlier: you flipped the paddle, then preinfusion water worked through the
  puck before the first drop landed. This offset is added when back‑dating the
  shot start, so the timer and graph line up with the moment you actually
  started the shot. Adjust it to match your machine's preinfusion setting as
  needed (roughly your typical paddle‑to‑first‑drip time); 0 starts the shot
  at the first drip.
- ④ **Smoothing** *(Off / Light / Medium / Strong, default Light)* — smoothing on
  the shot graph's line. Purely visual; detection and auto‑stop use the raw
  stream.
- ⑤ **Drop negative g/s** *(default on)* — clamps negative flow readings (cup
  bumps, scale noise) to zero on the graph.
- ⑥ **Oscilloscope graph** *(default on)* — the shot graph sweeps left→right and
  wraps, oscilloscope style. Off, it scrolls continuously instead.
- ⑦ **Window growth** *(Snap / Smooth / Continuous, default Continuous)* — how
  the shot graph's time window widens as a shot runs on past 15 s.
  **Continuous** keeps the whole shot filling the width, squeezing the trace
  as it lengthens. **Snap** jumps to 30, 45 and 60 s instead. **Smooth** makes
  the same jumps but eases each one over a second or so. Purely visual.

### Device settings

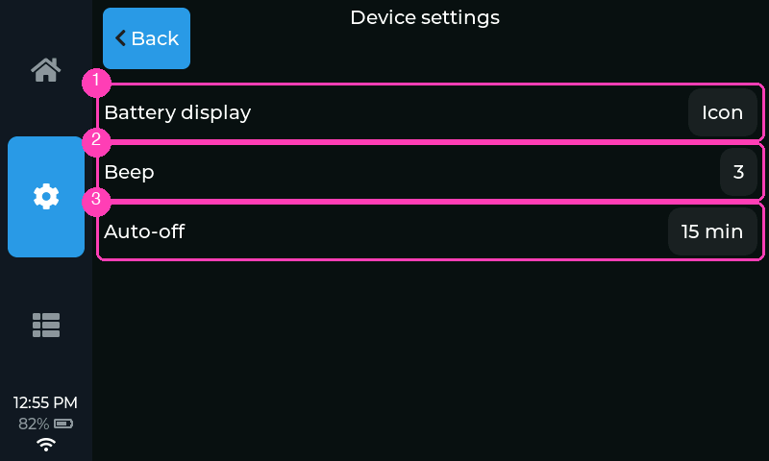
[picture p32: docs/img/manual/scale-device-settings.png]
Scale device settings — a Bookoo Themis's rows


① **Battery display** is Apollo's own: how the SCALE card on Home shows the
scale's battery — **Icon** (the level glyph, the default), **Percent**, or
**Icon + %**. It is available whether or not a scale is connected.

The rest are settings stored on the scale itself, adjusted over Bluetooth.
Which rows appear — and their value choices — depends on the scale model (a
Bookoo Themis's ② **Beep** and ③ **Auto‑off** shown above):

- **Bookoo Themis / Themis Ultra** — **Beep** (buzzer level Off / 1–3, the
  same range the Bookoo app offers) and **Auto‑off** (5–30 min). The scale
  also accepts levels 4–5 over Bluetooth, but the firmware plays those
  *quieter* than the real ones, so they aren't offered; one set elsewhere
  shows as `--`.
- **Acaia Umbra** — **Beep** (On / Off; also silences its tare/timer chirps),
  **Auto sleep** (Off / 1–30 min), and **Unit** (g / oz). The Acaia app can
  additionally set *power‑off* timers; those aren't offered here (a
  powered‑off scale can't be woken over Bluetooth) and show as `--` if set
  elsewhere.
- **Acaia Lunar / Pyxis** — **Beep** — the row shows the beep volume the
  scale stores (Off / 1–3), but over Bluetooth the beep can only be toggled:
  tapping cycles **off** and **on**, and *on* restores whatever volume was
  last set with the scale's own buttons (Bluetooth can't set a level — even
  the Acaia app is on/off only). Then **Auto sleep**
  (Off / 5–60 min), **Unit** (g / oz), and **Mode** — the scale's current
  weighing mode, shown for reference only (the Acaia protocol has no way to
  change mode remotely; use the scale's buttons).

**Unit** only changes what the *scale's own display* shows — Apollo always
works and displays in grams (an oz‑mode Acaia streams ounces over Bluetooth;
the firmware converts them back, so brew‑by‑weight targets stay correct).
Changed values may take a moment to be confirmed by the scale; if a change
doesn't stick, the row snaps back to what the scale reports.
- **Varia Aku** — none (no adjustable settings in its protocol; weight and
  battery only).

The scale owns these values: the rows show what it reports, so they read `--`
until the scale is connected (a **Connect** prompt appears right in the group
when it isn't — no scale paired yet, the group points you to Bluetooth
instead). Tap a value to advance to the next choice; the write goes to the
scale immediately and sticks like any change made from the scale's own
buttons. Like Tare, these rows are disabled while a shot is running.

### Per‑scale nuances & recommended daily workflow

The supported scales handle power and sleep differently, so the smoothest
end‑of‑day / morning routine differs by model. In every case, if the Micra has
an auto‑on schedule, the scale step below is the *only* thing you do — the
machine is already warming up when you arrive.

- **Acaia Lunar** — stays running for as long as Bluetooth is connected (it
  won't auto‑sleep on you mid‑connection). Recommended routine: just **power
  the scale off** when you're done and **power it on** in the morning — Apollo
  reconnects to it automatically.
- **Acaia Umbra** — can be used exactly like the Lunar, but it also has a real
  sleep mode that Apollo can wake it from. Recommended routine: tap
  **Disconnect** on Apollo's scale card when you're done (the Umbra won't
  sleep *while connected*, so disconnecting is what lets it doze — the card
  then shows `Sleeping`), and tap **Connect** in the morning, which wakes the
  Umbra over Bluetooth. The Umbra's battery lasts about a **week** in sleep
  mode — and once it's flat, Connect naturally can't wake it, so put it on a
  charger if it's been sitting.
- **Bookoo Themis** — has a sleep mode, but it genuinely powers down: Apollo
  **cannot** wake it with Connect. Treat it like the Lunar: leave Apollo
  connecting, **turn the scale on** in the morning and you're good; when
  you're done, just walk away — the scale sleeps on its own from inactivity.

---

## Settings → Apollo

Three short sub‑pages — **Display**, **Time & date**, and **WiFi** — so each
page fits on screen with little to no scrolling.

### Display

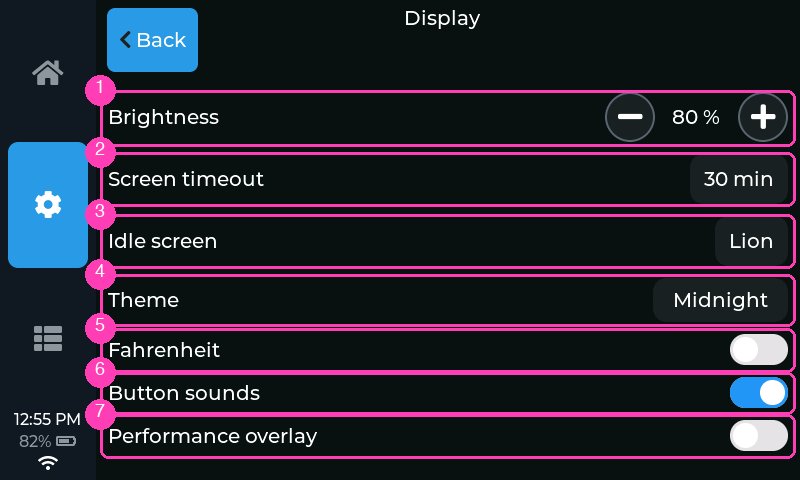
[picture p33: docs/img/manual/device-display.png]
Display settings


- ① **Brightness** *(dimmable boards)* — backlight level.
- ② **Screen timeout** *(Off / 1 / 5 / 15 / 30 min, default 30 min)* — after
  this idle time the idle screen starts (see the next row); any touch wakes the
  screen. A shot in progress never counts as idle, so the idle screen won't
  cover a live shot no matter how short the timeout — the countdown restarts
  when the shot ends.
- ③ **Idle screen** *(Lion / Apollo / Alternate / Dim / Off, default Lion; shown
  while Screen timeout is on)* — what the timeout shows. **Lion** and
  **Apollo** turn the backlight down (to 10 % on the S3 boards, 5 % on the
  P4s — low enough to read as asleep, high enough that the panel isn't
  mistaken for switched off) and bounce that drawing around a black screen,
  changing color at every wall it hits — the La Marzocco lion, or Apollo
  sipping an espresso. **Alternate** does the same, starting on either one and
  switching to the other every three minutes.
  **Dim** turns the backlight down the same way but leaves the normal screen
  showing, so you can still glance at the machine from across the kitchen.
  **Off** switches the backlight off entirely. On boards whose backlight can't
  be turned down, the drawings and Dim show at full brightness — choose Off
  there to go dark.

- ④ **Theme** — tap to cycle the color scheme: Midnight, Graphite, Espresso,
  Nord, Solarized, Plum, Forest, Rose, Mono (black & white), Contrast (high
  contrast), Ferrari, Sunset, Citrus, Modena, Gulf, Monaco, Ivory. The last
  four (plus Ferrari) are companions to the Micra body colors — the machine's
  paint as the accent: Ferrari red, Modena the yellow Micra, Gulf the light
  blue, Monaco the navy, Ivory the creme.
- ⑤ **Fahrenheit** *(default off)* — display unit for temperatures. Set‑points
  are still stored in Celsius.
- ⑥ **Button sounds** *(boards with a speaker; default on)* — click on button
  presses. (The other sound, the warm‑up chime, is under
  [Settings → Micra → Controls](#controls) since it's about the machine.) With
  button sounds off *and* the chime volume `Off`, the audio hardware stays
  powered down until the next restart.
- ⑦ **Performance overlay** *(default off)* — LVGL FPS/CPU overlay, for
  debugging.

### Time & date

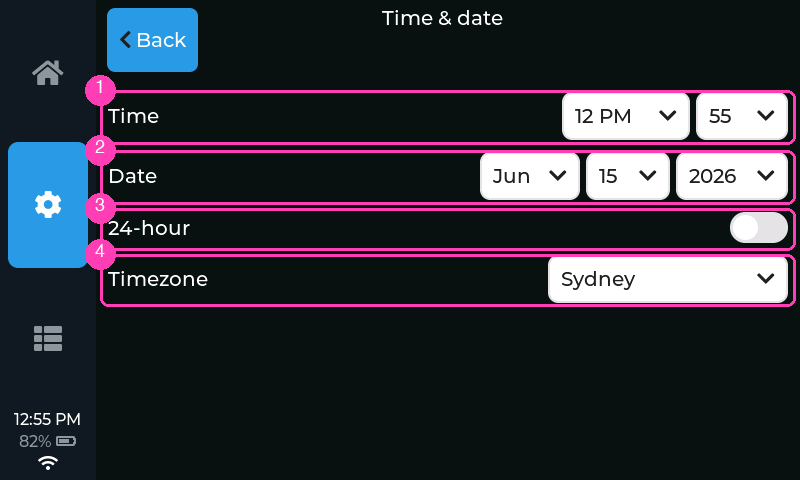
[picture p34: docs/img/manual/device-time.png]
Time & date settings


- ① **Time** — hour and minute pickers, to set the clock by hand. (With Wi‑Fi +
  NTP the clock sets itself on every boot; alternatively, boards with an RTC
  and an optional coin cell installed keep time through a power‑off.)
- ② **Date** — month / day / year pickers. NTP fills the date in automatically;
  without NTP a real date is needed for features that stamp records (shot
  history). Setting only the time leaves the date unset.
- ③ **24‑hour** *(default on)* — clock format.
- ④ **Timezone** — city picker (handles daylight saving). Governs how all
  times display and how NTP time is converted.

### WiFi

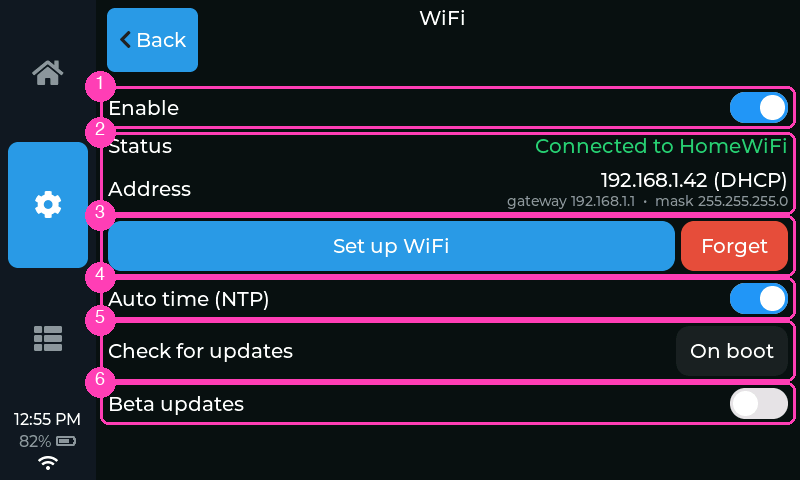
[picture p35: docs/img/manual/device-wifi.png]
WiFi settings


- ① **Enable** *(default off)* — join your home network. Used only for NTP time
  sync; all machine/scale control is local Bluetooth.
- ② **Status** — `Off`, `Connecting`, `Connected to ⟨network⟩`, or
  `Connection failed`. While connected an **Address** row appears beneath it
  with the IP and how it was assigned, *(DHCP)* or *(static)*, and the
  gateway and subnet mask in use — so a wrong static entry is visible here
  without opening the portal.
- ③ **Set up WiFi** — starts the device's own access point (`Micra-Setup`) and
  setup page for entering credentials (same flow as token entry: scan the
  QR code on the screen with your phone's camera and the page pops up on its
  own, or join the network and open the shown address). The page also offers
  your **time zone** (optional — the same list as Time & date), so one phone
  visit sets up WiFi and the clock:

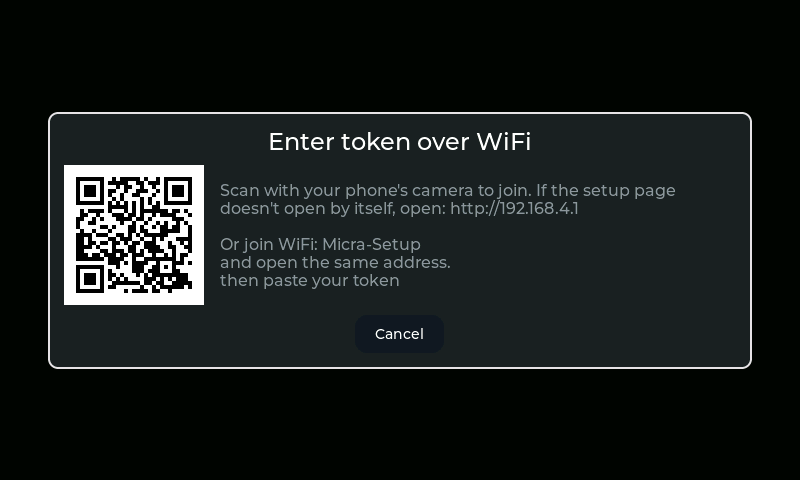
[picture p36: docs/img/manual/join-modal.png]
The QR join modal
  

  The page's last control is **Network address**: *automatic (DHCP)*, the
  default, or *static*. Static reveals four fields — IP address, subnet mask
  (255.255.255.0 on most home networks), gateway (your router), and an
  optional DNS server (the gateway when blank). A static address is handy if
  you bookmark the device's web page or reserve addresses on your router.
  There is no on‑device editor for these: to change or clear them, run
  **Set up WiFi** again — the page comes up with your network name and
  address settings pre‑filled, and the password can be left blank to keep the
  saved one, so a one‑field change is just that. Switching back to
  *automatic* is one tap. **Stats → Info** shows the
  current address with *(static)* or *(DHCP)* after it.

- ③ **Forget** — clears the saved network.
- ④ **Auto time (NTP)** *(default on)* — sync the clock over WiFi while
  connected. (The timezone it applies is set under **Time & date**.)
- ⑤ **Check for updates** *(default On boot)* — tap to cycle **Off / On boot /
  Daily / Hourly**. "On boot" checks once at startup; "Daily" and "Hourly" also
  re-check on that interval while the machine stays on — always during an idle
  moment (the idle screen is up), so they never get in the way. If Screen
  timeout is Off, the repeating checks never fire; the startup check and the
  manual button still work. Checks only run after an NTP sync has proven the
  internet is reachable. When a newer firmware exists, a notice shows the
  version and its release notes:

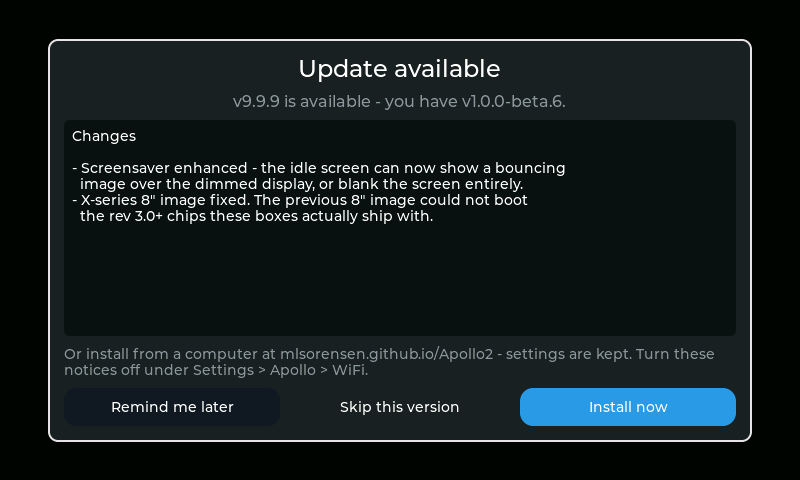
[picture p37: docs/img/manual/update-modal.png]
Update-available notice
  

  **Install now** installs it right on the device (see below); **Remind me
  later** closes the notice and offers again on the next check; **Skip this
  version** never offers that version again (the next release will). You can
  also check any time from **Stats → Info → Check for updates** — and if it
  can't reach the server it says "Couldn't check" rather than "up to date".

  **Installing** — after **Install now**, Apollo restarts into a minimal update
  screen: a progress bar while it downloads the new firmware, then a short
  **"screen goes dark for about 20 seconds — don't power off"** phase while it
  writes, then it restarts on the new version. Your settings, the paired
  machine, and shot history are kept, and a firmware that fails to boot rolls
  back to the old one automatically. **If an update fails partway** — a
  download that can't complete, or a new build that doesn't boot — the device
  simply comes back on the version it had, and the notice appears again at the
  next check; **Remind me later** or **Skip this version** keeps it out of the
  way while the cause is sorted out. (The check also won't offer a version
  until that version's image for your board is actually being served, so a
  release that is still publishing doesn't get offered early.) The
  [web flasher](https://mlsorensen.github.io/Apollo2/) remains the fallback for
  recovery and for a board's very first flash.

- ⑥ **Beta updates** *(default off; shown only while checks are on)* — also
  offer pre-release builds, named like `0.14.0-beta.1`. Betas ship the next
  release early so it can be tested on real machines; they are less proven than
  a normal release, and the notice, the install and the automatic roll-back on
  a firmware that won't boot all work exactly the same.

  Switching the toggle re-checks straight away, so the next notice matches the
  channel you picked. Turning it **off** while running a beta does not move you
  back on its own — the device stays on that build until a stable release is
  newer than it (`0.14.0` supersedes `0.14.0-beta.2`), which is usually days.
  To go back sooner, reflash the stable release from the
  [web flasher](https://mlsorensen.github.io/Apollo2/); your settings and
  history are kept.

### Backup

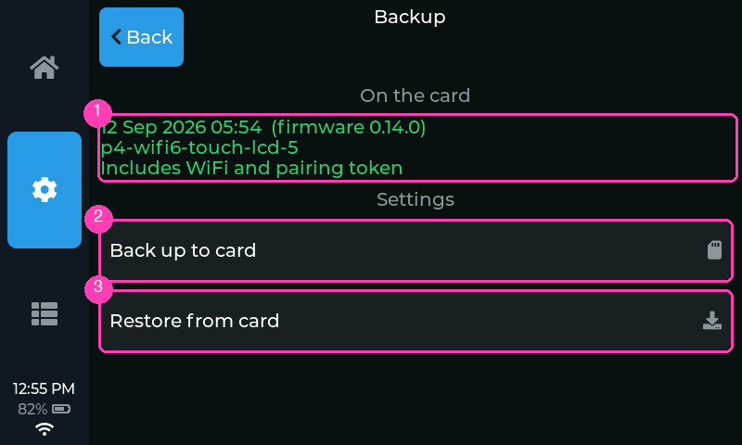
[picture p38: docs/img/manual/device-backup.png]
Backup settings


Your settings live inside Apollo, not on the memory card — so moving the card
to another one brings every shot across and none of your preferences. This page
copies the settings onto that same card, so a replacement can pick them up.

- ① **On the card** — what the inserted card holds: when the backup was taken,
  the firmware and board it was taken on, and whether it carries your WiFi
  network and pairing token. Otherwise `No card inserted` or `No settings
  backup on this card`.
- ② **Back up to card** — writes every setting to `/Apollo2/settings.txt`,
  beside your shots. It is plain text, readable on any computer:

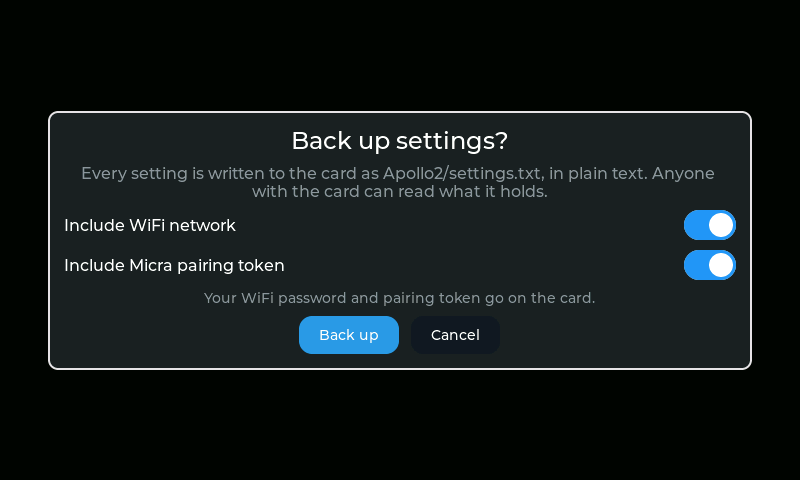
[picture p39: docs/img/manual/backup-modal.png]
The backup confirmation
  

  The two switches decide whether your **WiFi network** (name and password) and
  your **Micra pairing token** go onto the card with everything else. Both are
  on by default — the point of a backup is a replacement that just works — and
  turning one off means setting that up by hand later, which is the trade worth
  making if the card won't stay with the machine. Everything else (theme,
  chime, target weight, flush settings, schedule, timezone, and the rest)
  always travels.
- ③ **Restore from card** — replaces every setting on this Apollo with the
  backup, then restarts to apply it. Anything the backup doesn't carry — a
  setting added in a later firmware, or a credential you left out — goes back
  to its default. Greyed out when the card holds no backup.

A few things worth knowing:

- **Moving between boards is the point.** A backup taken on any supported board
  restores onto any other; nothing in it is board-specific.
- **A backup from newer firmware is refused** — update this Apollo first, then
  restore. Older backups are always fine.
- **Nothing happens on its own.** No automatic backup, no automatic restore;
  swapping cards between machines never changes a setting by itself.
- **Your shots aren't part of this** — they are already on the card, and a
  restore doesn't touch them.

### Root page

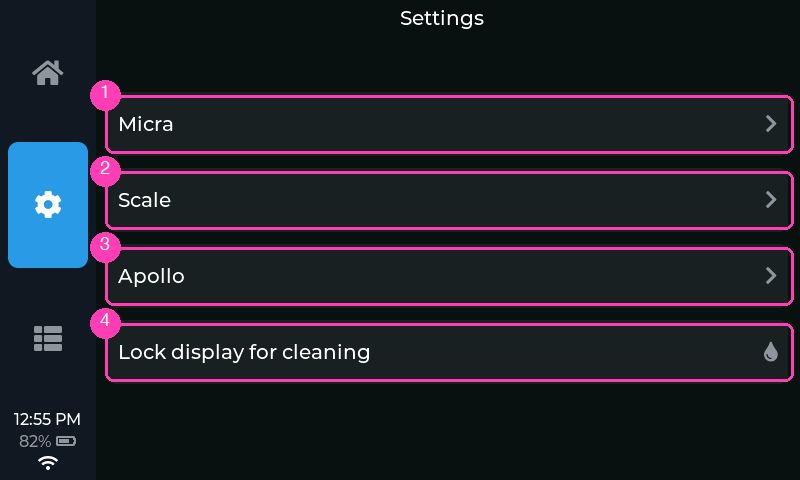
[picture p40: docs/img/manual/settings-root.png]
Settings root page


The rows ①–③ open the **Micra**, **Scale**, and **Device** pages above; one
action lives directly on the root:

> **Shortcut:** while you are anywhere inside Settings, tapping the Settings
> tab again returns straight to this root page — one tap instead of several
> Backs when crossing from, say, Apollo → Display to Micra → Controls.

- ④ **Lock display for cleaning** — disables touch for 30 seconds so you can
  wipe the screen. A full‑screen countdown shows the time remaining; the lock
  ends on its own (touching the screen does nothing until then).

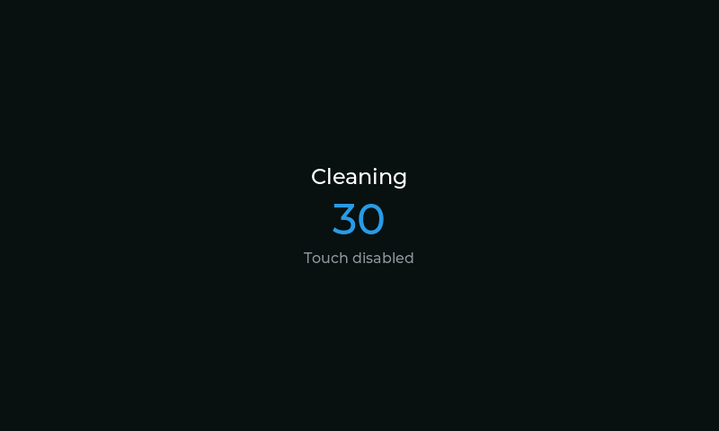
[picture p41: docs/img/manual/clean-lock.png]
The cleaning touch lock
  

---

## Stats

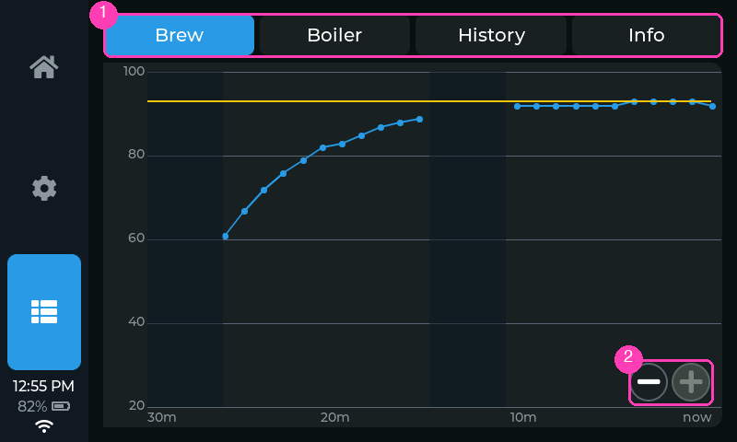
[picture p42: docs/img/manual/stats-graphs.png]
Temperature history


- **Brew / Boiler** — temperature history graphs, chosen with the selector ①.
  Tap **+/−** ② to zoom the time
  window; the set‑point is drawn as a reference line; gaps mean the machine was
  disconnected.

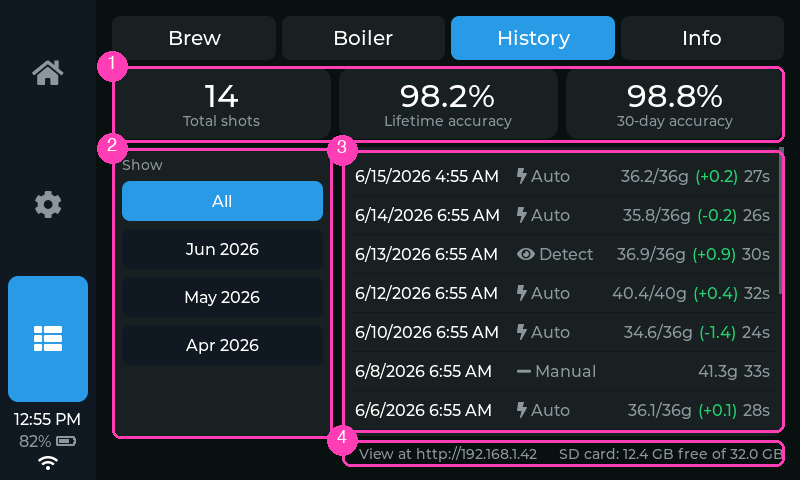
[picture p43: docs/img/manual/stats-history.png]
Shot history


- **History** — the shot log (boards with an SD‑card slot). Headline cards ① show
  lifetime totals: shots recorded, lifetime accuracy and 30‑day accuracy
  (actual vs target weight). Below, the shot list ③ with a calendar filter ② —
  **All** plus a button for each month that has shots, so an old month is one
  tap away instead of a long scroll. The footer ④ shows the web address and
  SD‑card space. Each row shows the signed miss against
  target — `36.2/36g (+0.2)` — green within 2 g, amber beyond, and how the
  shot was run: a bolt for an **Auto** shot (the paddle harness stopped it at
  weight) or an eye for a **Detect**ed one (inferred from the scale). Only
  those two modes record — a fully manual shot has no armed start/stop, so
  nothing is saved. Tap a shot for a full‑screen card with its
  result/target/diff, time, average flow, and the weight + flow graph:

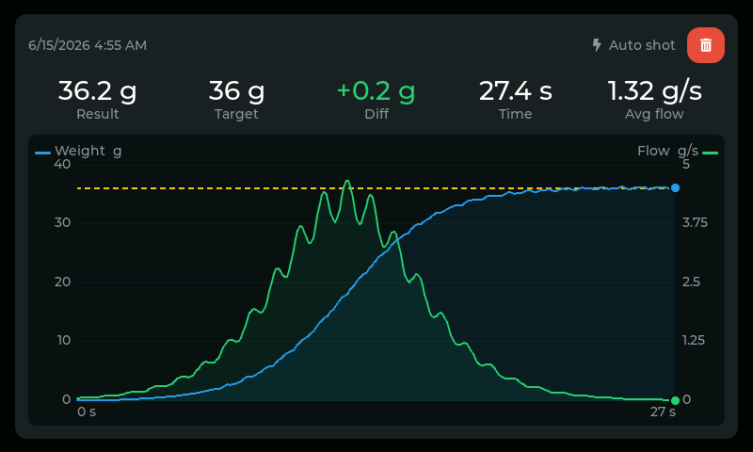
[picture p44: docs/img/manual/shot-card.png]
A shot's full-screen card
  

  - **SD card**: any size — a **small card is more than enough**. A shot is
    a few tens of KB, so even a 1 GB card holds decades of daily espresso;
    an old card from a drawer is perfect. Use a card formatted **FAT32**
    (FAT16 also works) — small cards usually ship that way. exFAT — the
    factory format of most cards over 32 GB — and NTFS are **not**
    supported: History detects what's on an unusable card and names it
    ("This SD card is exFAT‑formatted…") instead of pretending the slot is
    empty. Reformat on a computer; the device never formats or erases a card
    on its own.
  - **Hot‑swap friendly**: no reboot needed in either direction. The device
    looks for a card every 5 seconds, so a freshly inserted card is picked
    up within ~5 s; a removed card is likewise noticed within a few seconds
    and History switches back to the insert‑a‑card guidance. If the card
    fills up, new shots stop being saved and History says so.
  - **What's recorded and when**: recorded shots are viewable immediately —
    no clock needed. Recording NEW shots additionally needs a real date/time
    (NTP, or Settings → Apollo) — until the clock is set the footer warns
    that shots aren't being saved. Records live on the card under `/Apollo2`
    — an index CSV plus one samples CSV per shot — so the whole history can
    be read on any computer (graphs are drawn from the data by the device
    and the web page; nothing is pre‑rendered — the CSVs are the database).
  - **Delete a shot**: open its card and tap the red trash button, then
    confirm. The shot's files are removed from the card and the headline
    stats recalculate without it — handy for throwing out dial‑in or
    practice shots. This one *is* destructive (unlike Reset stats below).
  - **Reset stats**: tap any headline card. Non‑destructive — the three
    headline numbers restart from now (the Total card shows "Since ⟨date⟩")
    while every recorded shot stays on the card. Undo by deleting
    `Apollo2/stats_since.txt` on a computer.
  - **Browse from your phone or computer**: with WiFi connected, open
    `http://⟨device IP⟩/` (the IP is on **Stats → Info**). The device serves
    its own web page — the same stats, month filters, and shot list, with a
    live graph per shot, a **Download card** button that saves any shot as a
    PNG image (composed in your browser from the raw data), and CSV
    downloads — all styled to match whatever theme the device is currently
    using. The same built‑in web server also carries the setup pages during
    pairing/WiFi setup, so nothing conflicts.
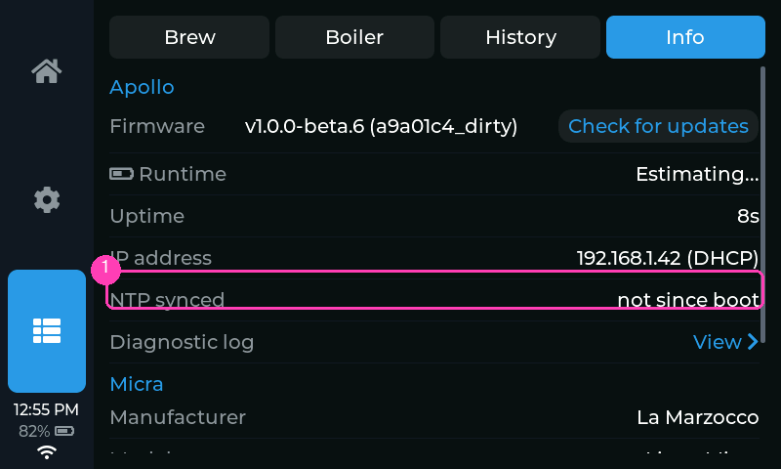
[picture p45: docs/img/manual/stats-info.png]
Device info


- **Info** — device details: our firmware version + git revision, uptime,
  battery/USB state with a runtime estimate, the **IP address** with how it
  was assigned — *(DHCP)* or *(static)*, see [WiFi](#wifi) —, **NTP synced** (how long ago the
  clock last synced over the internet, or "not since boot"), and the machine's
  Device Information (manufacturer, model, serial, firmware) read over Bluetooth.
  - **Check for updates** — next to the firmware version, tap it to check the
    releases site right now (needs WiFi + NTP). It reports back either an
    update notice or "You're on the latest firmware" — the same check the boot
    option runs, on demand.
  - ① **Diagnostic log** — tap **View** for the recent diagnostic log (the same
    messages the USB serial console prints), each line stamped with the time
    (or seconds‑since‑boot before the clock is set). The log lives in RAM:
    it survives as long as the device stays powered and holds the last
    64 KB — typically hours of normal operation — so "the paddle did nothing
    this morning" can be diagnosed after the fact without a serial cable.
    It does not survive a reboot. The on‑screen viewer shows the newest few
    KB; with WiFi connected, `http://⟨device IP⟩/log` serves the whole
    thing as plain text (there's also a **Log** link on the web page's
    header) — easy to copy into a bug report.
  - **Crash dumps** — if the firmware ever crashes and reboots, it saves a
    post‑mortem snapshot (a *coredump*) to internal flash first. On the next
    boot the log notes `crash dump stored`, and with WiFi connected a
    **Crash dump** link appears in the web page's header (next to **Log**;
    `http://⟨device IP⟩/coredump` directly also works) that downloads it as a
    file — attach it to a bug report and the exact cause can be pinpointed.
    The filename is a fingerprint of the build that *crashed* (dumps survive
    firmware upgrades, so that isn't always the version currently
    installed); it matches the `.appsha` files in the release's
    debug‑symbols archive, which is how the right decoding symbols are
    found. The dump survives reboots and even firmware
    upgrades until the next crash overwrites it;
    `http://⟨device IP⟩/coredump?erase=1` clears it manually.

---

## Brew‑by‑weight quick reference

| | Auto shot | Shot detect | Manual |
|---|---|---|---|
| Needs paddle wiring | **Yes** | No | No |
| Shot start | Paddle flip | Detected from weight (back‑dated by **Detect lead‑in**) | Paddle flip (wired) / — |
| Shot stop | **Automatic** at target − learned overshoot | You flip the paddle (pill flashes **Stop** at the right moment) | You flip the paddle |
| Auto‑tare at start | Yes | No (delta‑based) | No |
| Overshoot learning | Yes | No | No |
| Review graph + frozen weight | Yes | Yes | No |
| Auto flush eligible | Yes | Yes (wired boards) | No |

Wiring the paddle harness — parts, photos of the Micra's paddle loom, and
per‑board terminals — is covered in the [wiring guide](docs/WIRING.md), as
is the optional **Apollo Link** board for the P4 boards only (paddle
pass‑through when Apollo is off, power over the same cable; nothing to set
in the firmware). It does not work with the S3‑4.3C.

### Paddle pin protection & per‑unit remapping

- **Suggested: a 1 kΩ resistor in line with the paddle's sense wire** (at the
  screw terminal, between the board pin and the switch). It protects the
  input by limiting current from static or stray voltage on the wire —
  one cheap part, no effect on normal operation. The
  [wiring guide](docs/WIRING.md) shows a no‑solder way to add it with a
  4‑slot screw‑terminal block.
- **If a paddle pin ever does fail** (symptom: the paddle stops registering
  or behaves erratically while everything meters fine — the diagnostic log's
  `Paddle: raw sense ...` lines will show a line stuck or drifting on its
  own), the pins are **remappable per unit** without a custom firmware
  build: move the wire to a free GPIO on the header, connect the device over
  USB, and run

  ```
  make padsense PIN=50      # sense wire moved to GPIO50 (example)
  make paddrive PIN=49      # drive wire, same idea
  make padsense PIN=-1      # revert to the board default
  ```

  (or type `padsense=50` into any serial monitor). The setting is stored in
  the device's settings memory — it survives reflashes and web‑flasher
  upgrades, so stock releases keep working on a remapped unit — and takes
  effect on the next boot, which logs it: `Paddle: sense GPIO50 (NVS
  override)`. The board's default pins stay unchanged for everyone else.

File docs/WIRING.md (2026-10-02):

# Wiring the paddle (Auto shot)

This is the **optional** hardware step that unlocks **Auto shot** (the
firmware stops the shot at your target weight) and **auto‑flush**. Apollo sits
*in the middle* of the Micra's paddle circuit: the physical paddle switch now
feeds Apollo's sense input, and Apollo's isolated output stands in for the
paddle on the Micra's controller. Nothing else about the machine changes, and
**Shot detect** works fine without any of this.

The paddle circuit itself is low‑voltage (the Micra's controller puts ~5 V on
it), but you will have the machine open — **unplug the Micra first**.

> **Disclaimer:** this is a DIY modification. Done properly it is safe and
> fully reversible, but it is not endorsed by La Marzocco and you do it
> entirely at your own risk.

> **Note:** while this wiring is in place, the paddle works **only through
> Apollo** — with the controller off, unplugged, or missing, flipping the
> paddle does nothing. Because the tap is made with pluggable connectors,
> undoing it is easy: open the top and temporarily reconnect the paddle's
> original connectors to run the machine without Apollo.
> (The optional [Apollo Link](#apollo-link-optional-p4-boards) board at the
> end of this guide removes this caveat on the P4 boards: it hands the paddle back to the
> machine whenever Apollo is off. It does not exist for the S3‑4.3C.)

## Parts

- A **3‑conductor cable** to run between Apollo and the machine — for example
  [this one](https://a.co/d/07cSW1AY), but any 3‑conductor cable works.
- **Bullet connectors** (or your favorite splice) for the in‑machine pigtail,
  so everything stays pluggable and reversible.
- **P4 boards only**: a single‑channel **PC817‑style opto‑isolator module**,
  e.g. [this one](https://a.co/d/03qHqcyM) — anything similar works. (The
  S3‑4.3C has isolators built in; no module needed.) A
  [2.54 mm screw‑terminal block](https://a.co/d/0eVdsD4h) that clips onto the
  P4's GPIO header makes the board‑side connection clean and solder‑free.

(P4 boards have an optional alternative to the module and the splice: the
[Apollo Link](#apollo-link-optional-p4-boards) board, described at the end
of this guide.)

Although there are **four** connections at the machine end (Micra white,
Micra black, and the two paddle‑switch wires), one 3‑conductor cable is all
you need — **ground is shared**. It just means the ground conductor gets
**two connectors** at the machine end.

## Inside the Micra

Remove the Micra's top panel. Toward the front you'll find a **black loom**
carrying a thin **white** and a thin **black** wire, ending in connectors that
join the paddle switch:

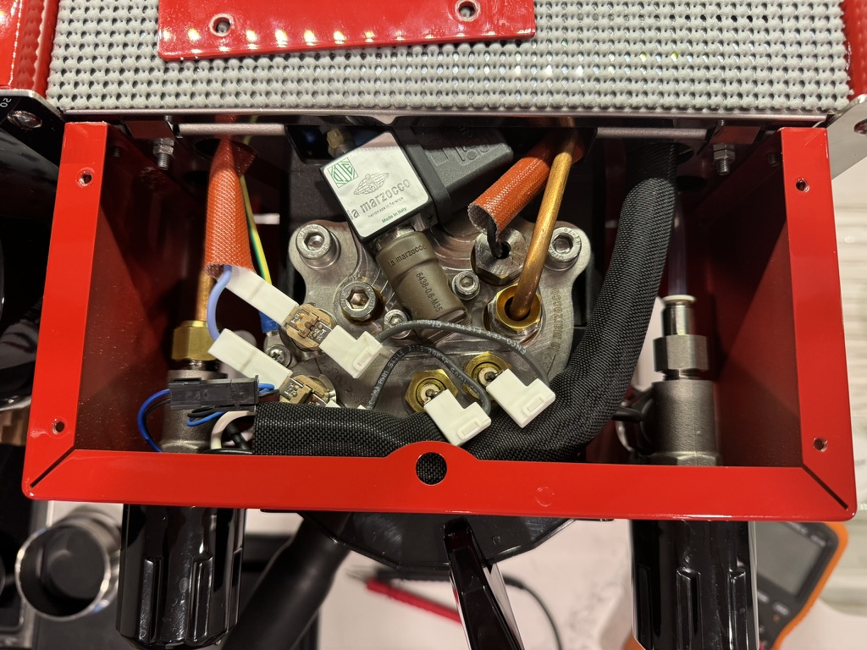
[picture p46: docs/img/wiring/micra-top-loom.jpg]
Micra top open — the black loom


Two connectors can be temporarily unplugged for easier access to the loom
(arrows):

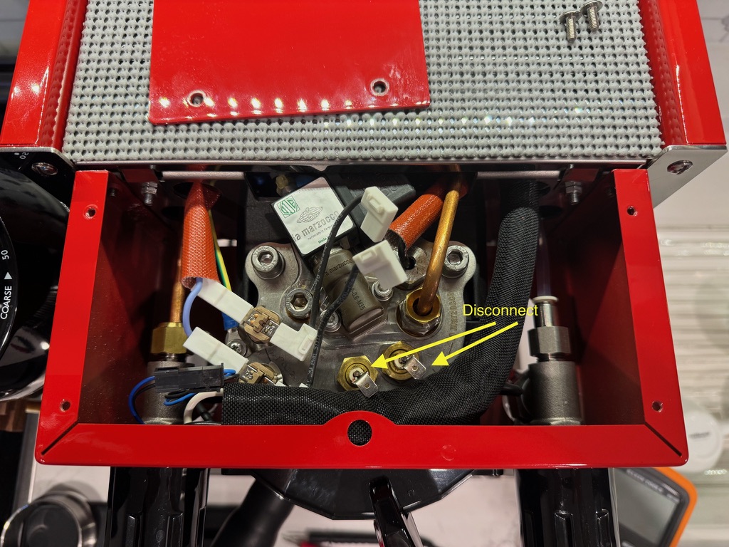
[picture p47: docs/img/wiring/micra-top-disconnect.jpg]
Temporarily disconnect these for access


Prepare your cable with bullet connectors, run it into the machine, unplug the
paddle connectors, and wire Apollo in the middle as described below. What
you're looking at:

- The **thin wires** go to the Micra's controller: **white = +5 V**,
  **black = ground**.
- The **thicker wires** go to the physical paddle switch. The paddle
  connectors have no polarity — either direction works.

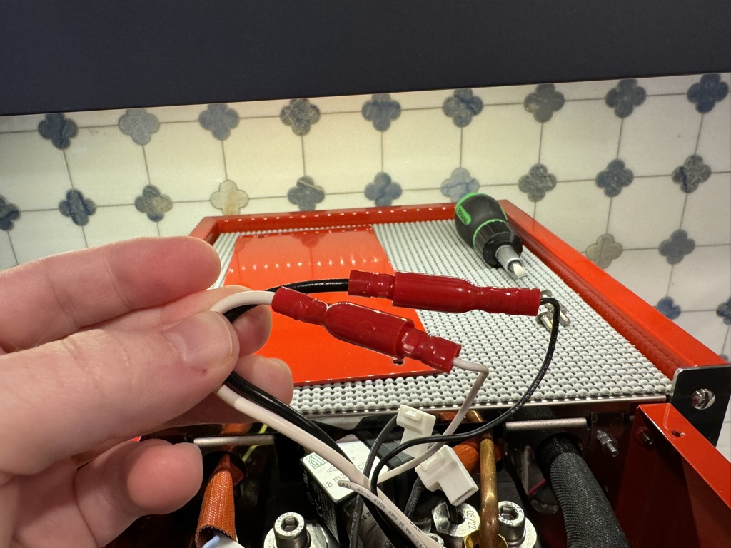
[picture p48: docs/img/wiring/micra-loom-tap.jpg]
Loom pulled up, tapped with bullet connectors


## ESP32‑S3‑Touch‑LCD‑4.3C / 4.3C‑BOX (built‑in isolators)

The 4.3C's isolated DI/DO terminal block already contains the opto‑isolators,
so the 3‑conductor cable is the whole job:

| Board terminal | Connects to |
|---|---|
| **DO0** | Micra **white** (thin wire, controller +5 V) |
| **DI0** | one paddle‑switch wire |
| **GND** | Micra **black** (thin wire) **and** the other paddle‑switch wire (shared) |

Note: use the **GND** terminal for the paddle return, **not DI COM** — DI COM
is internally biased on this board, and the paddle must close DI0 to ground to
be sensed.

A finished 4.3C cable — bare wires for the screw terminals at the board end,
bullet connectors at the machine end (two on the shared ground conductor):

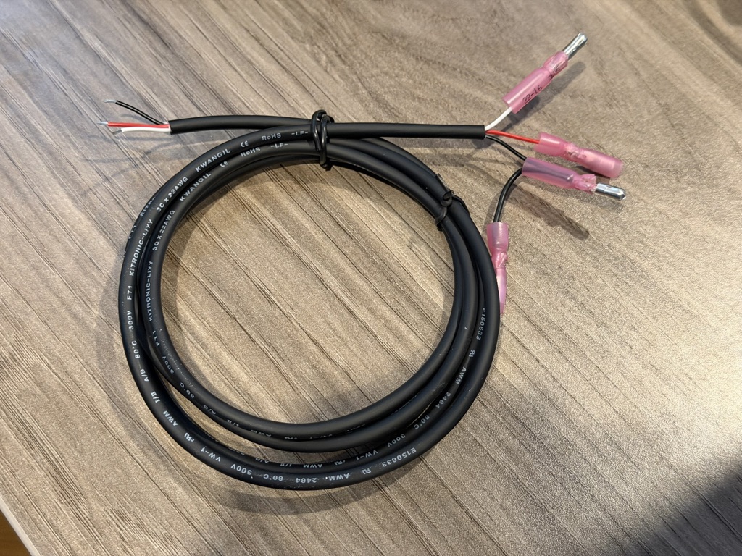
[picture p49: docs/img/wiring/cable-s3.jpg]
Finished 4.3C cable


## ESP32‑P4 boards (external opto module)

On the P4‑WIFI6‑Touch‑LCD‑5 (and the 4.3), the paddle uses three native pins
that sit **side by side** on the corner of the GPIO header — **GND, GPIO 52,
GPIO 51**, in that order on the silkscreen — so a
[2.54 mm 3‑pin screw‑terminal block](https://a.co/d/0eVdsD4h) clips straight
onto them, no soldering. The X‑series boxes (7"/8") use the **same three
pins**: on their 40‑pin header one pin column runs GND, IO52, IO51 in a row
near the header's end (per the schematic — the photos below show the 5";
double‑check the silkscreen before clipping on):

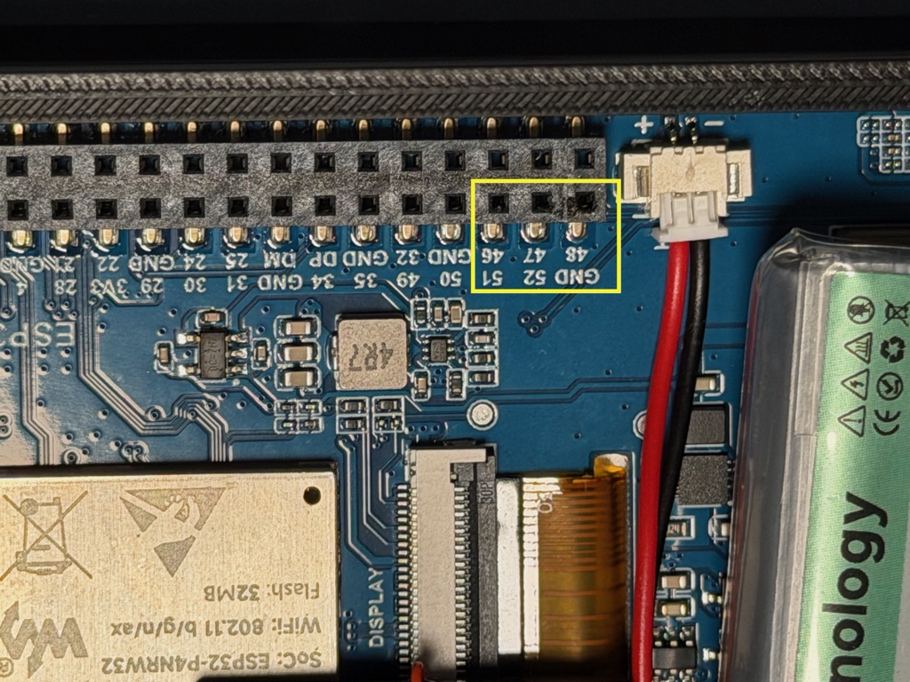
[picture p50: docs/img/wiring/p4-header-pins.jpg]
The P4 header corner — GND, 52, 51 in a row


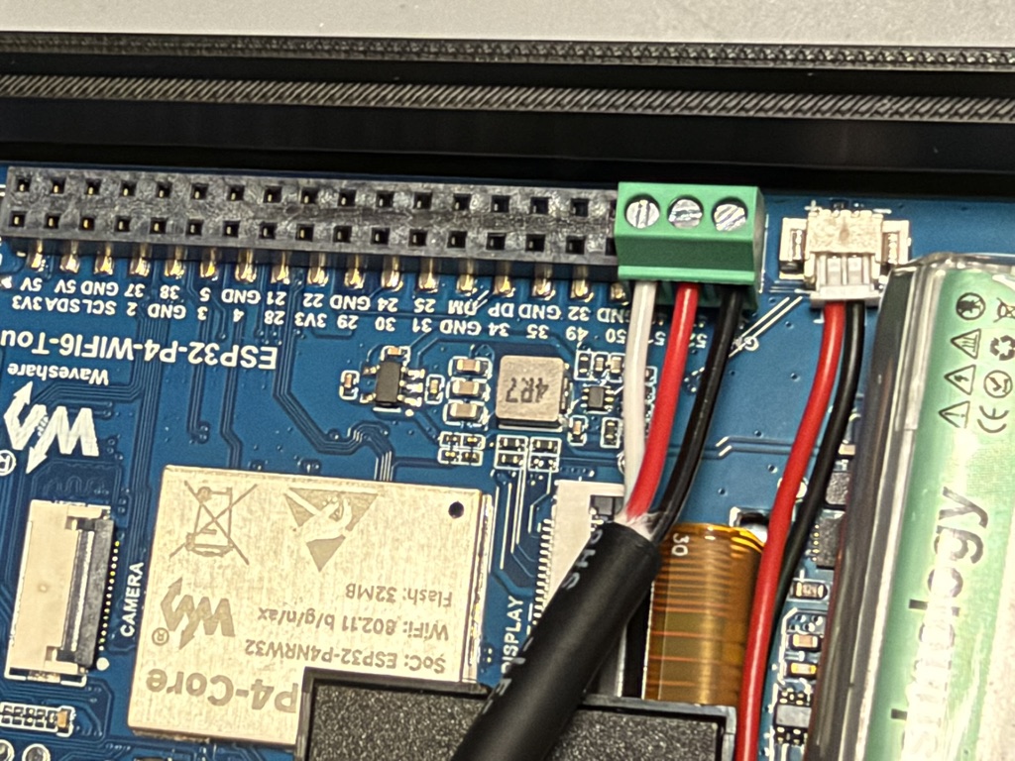
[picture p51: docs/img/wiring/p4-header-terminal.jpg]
Screw-terminal block on the pins, cable attached


The cable can run out through a hole in the 3D‑printed backplate. From there,
the opto module provides the isolation:

Apollo P4 → opto module → Micra wiring

In detail:

- **Drive (Apollo → Micra):** Apollo **GPIO 52** → opto module input **IO**,
  and Apollo **GND** → the module's input **GND**. On the output side leave
  **VCC unconnected** ("VCC suspended") so OUT/GND form an isolated dry
  contact: module **OUT** → Micra **white**, module output **GND** → Micra
  **black**. When Apollo raises GPIO 52, the contact closes — exactly like the
  paddle.
- **Sense (paddle → Apollo):** one paddle‑switch wire → Apollo **GPIO 51**,
  the other → Apollo **GND**. The physical paddle now touches only Apollo,
  never the Micra. Suggested: a 1 kΩ resistor in line with this wire at the
  terminal block — it protects the input by limiting current from static or
  stray voltage on the wire, and has no effect on normal operation.
- **If a pin ever fails anyway**, both paddle pins can be remapped per unit
  (no custom build): move the wire to a free header GPIO and run
  `make padsense PIN=<n>` / `make paddrive PIN=<n>` with the board on USB —
  see the manual's "Paddle pin protection & per‑unit remapping" section.

**No‑solder way to add that resistor:** use a **4‑slot** screw‑terminal block
instead of the 3‑slot. Positions 1–3 land on GND / 52 / 51 as usual; position
4 hangs past the used pins — **bend or cut off its header pin** so it doesn't
insert into the board. Screw the **1 kΩ resistor** in as a jumper between
positions 3 and 4, then land the paddle‑sense wire in position **4** instead
of 3: the signal reaches GPIO 51 only through the resistor, and nothing was
soldered or spliced.

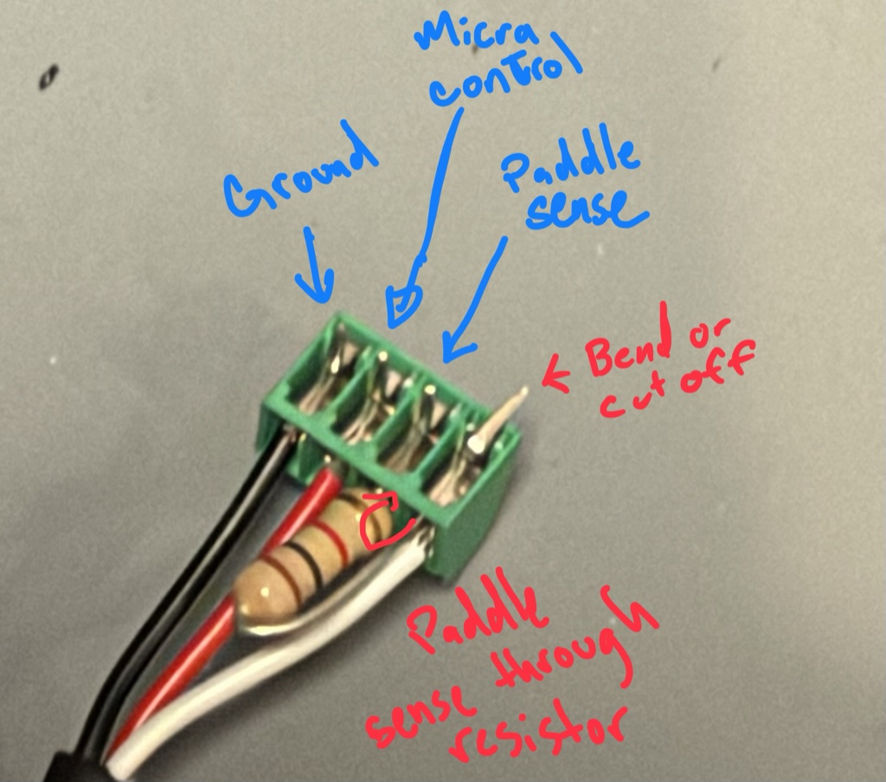
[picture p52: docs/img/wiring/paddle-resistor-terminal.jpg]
4-slot terminal block with the resistor jumpering positions 3-4 and the position-4 pin bent clear


A finished P4 cable with the opto module spliced in near the machine end
(shown before wrapping the module in heat‑shrink — do wrap it, so nothing can
short out inside the machine). Of the cable's conductors, **red + black feed
the opto module's input** — that pair carries Apollo's drive and becomes the
Micra's paddle signal on the isolated side — while **white + the second
black** run to the physical paddle switch:

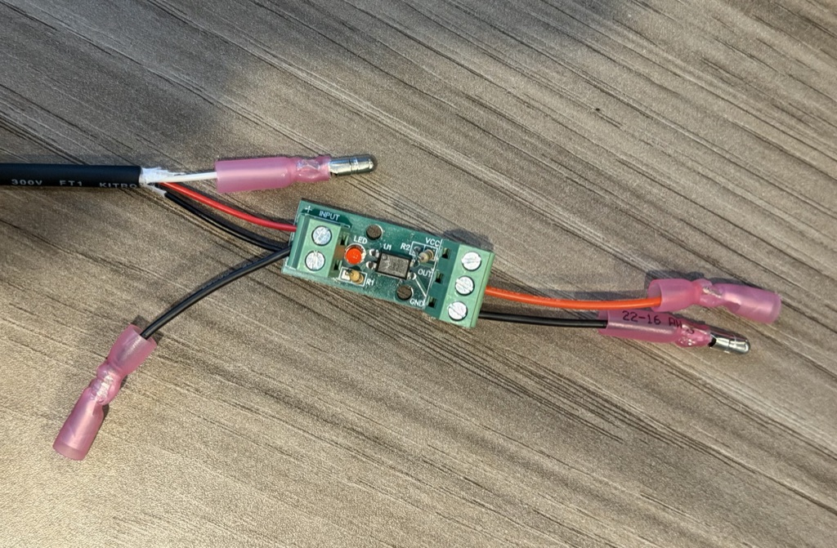
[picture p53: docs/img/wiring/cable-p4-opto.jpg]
Finished P4 cable with inline opto module


**Keep the opto module away from heat when installing it.** An opto‑isolator
loses transfer ratio as it warms, so one that heat‑soaks can stop registering
"paddle on" until it cools — a failure that looks exactly like a broken cable
and then fixes itself. Inside the machine is fine; sitting against the brew
head, a boiler, or any other heat‑producing surface is not. **Mount it low
and away from the brew head** — there is open space below the hot‑water pipe
and the steam wand that works well — and where clearance is tight, a piece of
neoprene sheet between the module and the nearest hot surface does the job.

## Bench‑test before installing

The whole cable can be validated before it ever touches the machine. Connect
it to Apollo, power up, and turn on **Settings → Micra → Settings → Wired
paddle**. Apollo relays the paddle regardless of anything else, so:

1. **Touch the two paddle‑sense wires together** — to Apollo that's the
   paddle flipping ON. On a P4 build the opto module's **red LED lights**
   while they're touching.
2. **Meter the Micra side**: with a multimeter in continuity mode across the
   two machine‑side connectors (the ones destined for the Micra's white and
   black), you should read a **closed circuit** while the sense wires touch
   and **open** when you separate them.

That's the whole contract — paddle closed ⇒ Micra‑side contact closed — so if
both steps behave, the install will work.

## Closing up

Tuck the finished wiring down into the machine, **reconnect any connectors
you unplugged** for loom access, and put the top panel back on.

## Afterwards

With **Wired paddle** on (from the bench test above), the **Auto shot** mode
appears on the Home shot pill and **Auto flush** becomes available. See the
[manual](../MANUAL.md) for what each mode does.

## Apollo Link (optional, P4 boards)

**You do not need this, and it is P4‑only.** The opto cable above is the
simplest way to wire the paddle and it is what most installs use. Apollo
Link is a small open‑hardware board that replaces the opto module and the
DIY splice on the **P4 boards (5, 4.3 and the X boxes)** for people who want
two extra things. **It does not work with the ESP32‑S3‑Touch‑LCD‑4.3C**:
that box has no header pins for it and already has its own isolators, so
its paddle wiring is the three screw‑terminal wires described above and
nothing else.

- **The paddle keeps working without Apollo.** Solid‑state relays on the
  Link wire the paddle straight to the Micra in copper whenever Apollo is
  off, unplugged, rebooting or mid‑update, and hand it to Apollo only while
  Apollo is running. The "paddle works only through Apollo" caveat at the
  top of this page no longer applies.
- **One cable, no USB lead at the display.** A USB‑C power adapter plugs
  into the Link, and the same 5‑wire cable that carries the paddle also
  powers Apollo through its GPIO header.

Everything about it lives in the repo under
[`hardware/paddle-bridge`](../hardware/paddle-bridge): the KiCad schematic
and layout, a Mouser‑ready BOM (13 line items) and the gerbers to have the
board made. It is young — the first boards were built in October 2026 — so
expect rough edges.

**Parts:** the Link board, assembled; two JST PH housings (PHR‑5 for the
Apollo side, PHR‑4 for the machine side) with their crimp contacts; a
5‑conductor 24 AWG cable; a USB‑C 5 V adapter rated **1.5 A or more** (a
battery unit draws about 1 A while charging; battery‑less, about 0.6 A); and a
2 × 7 plug for the Apollo end of the cable — an IDC plug such as the Omron
XG2A‑1401 with 28 AWG wire lies flat against the board (a 2.54 mm crimp
housing works too, standing taller).

**Apollo end.** The Link uses a second set of pins at the **5 V end** of the
P4's 40‑pin header (the end nearest the RTC connector). The header's
silkscreen prints the GPIO *names*, so the five wires land on:

| wire | header label |
|---|---|
| 5V | **5V** (either of the two) |
| GND | **GND** (the one beside 5V, or the one beside 2) |
| DRV | **3** (GPIO 3) |
| SENSE | **5** (GPIO 5) |
| CTRL | **4** (GPIO 4) |

Those sit inside a 2 × 7 rectangle running from **4 … 3V3** on the outer row
and **GND … 5V** on the inner row, so a 14‑way IDC plug (Omron XG2A‑1401)
covers them in one go; the other positions in the block stay unwired, since
they carry the I2C bus (**SCL**, **SDA**), the console UART (**37**, **38**),
**2** and 3.3 V. The corner pins the opto cable uses (**GND / 52 / 51**) stay
free — the firmware drives both sets at once, so there is nothing to set,
and either cable works on any P4 unit.

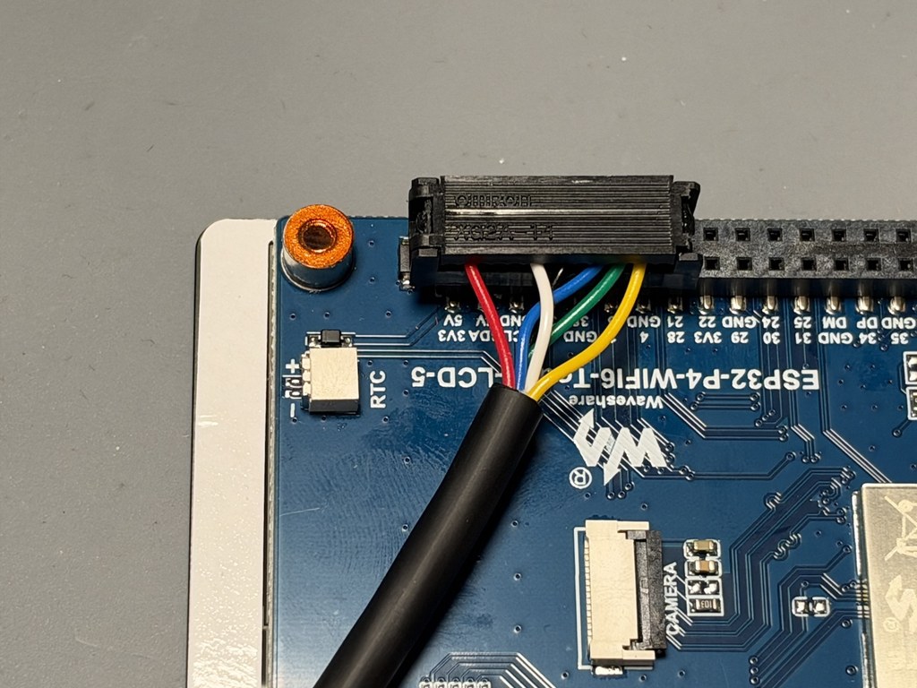
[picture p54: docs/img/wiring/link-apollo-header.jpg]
Apollo Link plug on the 5 V end of the P4 header


**Link end.** J1 (marked *APOLLO*) takes the five wires in the order on its
silkscreen: GND, 5V, DRV, SENSE, CTRL. J2 (marked *Micra: paddle tap*)
goes to the machine: **P1** and **P2** to the two paddle‑switch wires,
**MW** and **MB** to the Micra's white and black. The USB‑C port marked
*PWR* is the 5 V supply.

**The green LED** means *Apollo has the paddle*. Apollo switches it on a
few seconds into every boot and keeps it on for as long as the firmware is
running, whatever the **Wired paddle** setting — so with Apollo up it should
simply always be lit. Dark means the paddle is wired to the Micra in copper:
Apollo is off, unplugged, mid‑update, or the Apollo‑end plug isn't seated on
the right pins. It says nothing about shots; it doesn't flicker with the
paddle.

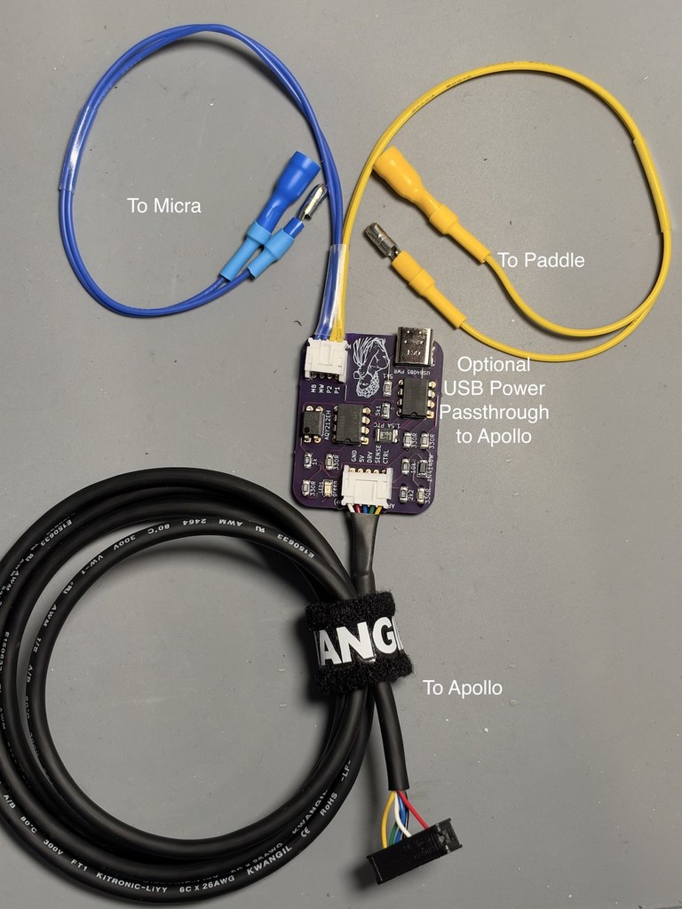
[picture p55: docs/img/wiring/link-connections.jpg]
Apollo Link with its cables: machine side, paddle, USB power, Apollo


**Battery units:** whether a fitted battery charges from the Link depends on
the board. On the **X 8"** it does — measured: 4.93 V at 1.0 A at the Link's
input while running and charging. On the **P4‑5 and P4‑4.3** it does
**not**: header power does not reach their charger, so a battery there
charges only from the board's own USB‑C. Size the adapter for the charging
case regardless (see Parts); battery‑less units draw about 0.6 A.

### Bench‑test the Link

Same idea as the opto cable, but the Link has a second thing to prove: that
the paddle works *without* Apollo. Set up with a multimeter in continuity
mode across the two **Micra‑side** wires (the ones for MW and MB), and use
the two **paddle** wires (P1 and P2) touched together as the paddle.

1. **Apollo off.** Power the Link from its USB‑C but leave Apollo unplugged
   from the Link's *APOLLO* connector (or simply powered down). Touch P1 to
   P2: the meter must read **closed**, and the Link's green LED stays
   **dark**. That is the paddle reaching the Micra in copper — the machine
   would work exactly as stock.
2. **Apollo on.** Plug Apollo into the Link and let it boot (with nothing
   on Apollo's own USB‑C, it is now running from the Link — that proves the
   power path). The green LED comes **on**: Apollo owns the paddle. Turn on
   **Settings → Micra → Controls → Wired paddle**.
3. **Paddle through Apollo.** Touch P1 to P2 again: the **shot timer on the
   Home screen starts** (Apollo saw the paddle) and the meter reads
   **closed** again — but this time Apollo closed the Micra line itself.
   Separate the wires: the timer stops and the meter opens.

If all three behave, the install will work, and so will the machine on the
days Apollo is unplugged.

### Installing it

**Plug in the Link's USB power only after verifying the wiring.** Connect
everything else — the plug on Apollo, the paddle and Micra wires on J2 — with
Apollo running from its own USB‑C or battery and the Link's *PWR* port empty.
Check that it works: the green LED is lit, and flipping the paddle starts the
shot timer (or pops the Wired‑paddle reminder if that switch is off). If
you'd rather not involve the machine yet, a multimeter in continuity mode
across the MW and MB wires stands in for the Micra: it reads closed while the
paddle is on, and the timer still runs. Only then plug the adapter into the
Link. A working Link proves every wire landed on the right pin *before* the
adapter's 5 V goes through it; the Apollo end is a plain 2 × 7 plug with
nothing to stop it going in rotated, and a rotated plug with power behind it
can destroy the P4. Without that power it can't.

Mount the Link where you would mount the opto module — low in the machine,
away from the brew head (the relays are rated to 85 °C) — then close up and
set **Wired paddle** exactly as in the sections above. Everything in the
manual about Auto shot, auto‑flush and cleaning applies unchanged; the only
visible difference is that the paddle keeps working when Apollo is off.

### If something's off

| What you see | Likely cause | Do |
|---|---|---|
| The pump runs the moment Apollo boots, no paddle touched | The plug is rotated 180° (the DRV wire is on a 5 V pin) | Unplug the Apollo end, turn it around |
| Green LED dark while Apollo is running | The plug is shifted along the header, or the J1 wires are in the wrong order | Re‑seat it one pair in from the 5 V end; check J1 reads GND, 5V, DRV, SENSE, CTRL |
| LED lit, paddle flips do nothing on Apollo | SENSE not on GPIO 5, or P1/P2 not on the paddle wires | Check the plug position and the J2 wires |
| Touch or sound stops while the Link is plugged in | A wire landed on SCL/SDA — the plug is rotated | Unplug it; nothing is damaged without the Link's power |
| Apollo runs from its own USB but not from the Link | 5V/GND not on the 5V/GND pins, or the PTC has tripped | Fix the plug; a tripped PTC resets by itself once the adapter is unplugged |
| "USB power" shown but a fitted battery never charges | Expected — the Link does not charge a battery | Charge from Apollo's own USB‑C |

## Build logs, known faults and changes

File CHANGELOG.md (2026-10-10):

# Changelog

Firmware releases. The section matching a release tag becomes that GitHub
Release's notes (see `.github/workflows/firmware-release.yml`), so keep the
heading format `## vX.Y.Z` exactly — write for someone using the machine, not
for someone reading the diff. These notes are also shown ON THE DEVICE, whose
fonts are ASCII-only: stick to characters `sanitize_notes()` (src/ui/app.cpp)
maps — plain ASCII plus `— – → … × ' "` — or they render as empty boxes.

## v1.0.0

### Changes

- **Scheduled on and standby.** Settings → Micra → Schedule turns the machine
  on and to standby at set times, daily or per weekday, with a warm-up lead.
- **Auto-standby after the last shot.** The machine can go to standby a set
  time after the last shot, with the minutes left shown on the Home card.
- **Apollo Link.** The P4 boards also drive the paddle bridge on the 5V end of
  the 40-pin header, so one cable carries the paddle and powers the remote.
- **Auto flush ignores the paddle once it is running.** Flipping the paddle
  back to rest no longer cuts the rinse short; the Home Flush button reads
  Stop to end it early.
- **No scale, Manual mode.** With no scale paired the firmware runs in Manual
  mode, so a paddle flip is never refused for a missing scale.
- **Wired paddle reminder.** The first paddle flip seen with Wired paddle off
  pops a one-time hint pointing at the switch.
- **Cleaning page says when it can't act.** With Wired paddle off, Auto flush
  and Flush delay are greyed out with a line saying what to switch on.
- **Scale battery as icon, percent or both.** Settings → Scale → Device
  settings → Battery display picks how the SCALE card shows it.
- **Static IP address.** The WiFi setup page offers a static address with IP,
  mask, gateway and DNS, and Stats → Info shows which is in use.
- **Welcome screen on a new unit.** Until a Micra is paired, each boot lists
  the three setup steps — WiFi, Micra, scale — with a button for each.
- **Settings tab doubles as a home button.** Tapping the Settings tab while
  inside Settings jumps straight back to its root page.
- **P4-5 and P4-4.3 on the newer ESP32-P4 chip.** Boards with v3 silicon get
  their own image, and the web flasher's Detect picks the right one.
- **Web flasher fixed for newer P4 boards.** Flashing a rev v3 ESP32-P4 from
  the browser no longer fails after the confirmation dialogs.
- **Updates are only offered once they are really there.** The check confirms
  your board's image is being served before showing the notice.
- **Scheduled turn-on after a lost connection.** The device now reconnects to
  the Micra while the screen is asleep, and a skipped trigger is logged with
  the reason.
- **Crash-dump download no longer crashes P4 boards.** Fetching the crash dump
  from the device's web page now downloads instead of rebooting the board.

## v0.14.2

### Changes

- **Shot graph grows smoothly.** Past 15 s the shot graph's window now widens
  continuously, so the whole shot always fills the width — no more jumps to
  30, 45 and 60 s. A new Settings → Scale → Shot settings row, Window growth,
  brings back the jumps (Snap) or eases them (Smooth).

## v0.14.1

### Changes

- **Apollo joins the idle screen.** Settings > Device > Display > **Idle
  screen** now offers **Lion**, **Apollo** (a new drawing of Apollo sipping an
  espresso) or **Alternate**, which switches between the two every three minutes,
  alongside Dim and Off. Existing Logo setups become Lion.
- **A bigger, smoother idle screen.** The bouncing drawing is half again as
  tall, moves one pixel per frame, and no longer redraws the hidden Home
  screen underneath itself, so it holds its frame rate at the larger size.
  Waking is as quick as a tab switch.

## v0.14.0

Everything since v0.13.0, including what the four betas carried.

### Changes

- **Beta updates.** Settings > Apollo > WiFi has a **Beta updates** switch;
  with it on, Apollo also offers pre-release builds. Off by default.
- **Back up your settings to the memory card.** Settings > Apollo > **Backup**
  writes every preference to the card and **Restore from card** puts them on
  another Apollo, so replacing the hardware no longer means setting up again.
  WiFi and the Micra token are each a switch on the confirmation.
- **The Dim idle screen keeps the screen on.** The backlight drops to the low
  level and the normal screen stays visible; the first touch still only wakes it.
- **Memory failures now leave evidence.** When an allocation fails, Apollo
  records who asked and what was filling memory, and prints it after the
  reboot as `memfail:` lines in the on-device log.

### Fixes

- **Joining the Micra-Setup WiFi is quick again.** Apollo no longer keeps
  trying to reach the machine and scale over Bluetooth while the setup
  network is up, which was starving it of radio time.
- **The screen stays on during setup.** The idle screen no longer kicks in
  while the token or WiFi setup instructions are showing.
- **The setup instructions cover the page not opening.** If the setup page
  doesn't appear after scanning the QR code, the screen now says to open
  the shown address.

## v0.14.0-beta.4

### Changes

- **Memory failures now leave evidence.** When an allocation fails, Apollo
  records who asked and what was filling memory, and prints it after the
  reboot as `memfail:` lines in the on-device log.

## v0.14.0-beta.3

### Changes

- **Settings backup: the notices can be read now.** Backing up and restoring
  both finish in a fraction of a second, so the "Backing up" / "Restoring"
  notice and the result that followed it went by in a single flash. Each one
  now stays on screen long enough to read, and after a restore the "Settings
  restored" notice holds for eight seconds before Apollo restarts.
- The backup confirmation's wording is clearer about what ends up on the card.

## v0.14.0-beta.2

### Changes

- **Back up your settings to the memory card.** Settings > Apollo > **Backup**
  writes every preference — paired machine, scale, theme, chime, target weight,
  flush and brew settings, timezone — to `/Apollo2/settings.txt` on the same
  card your shots are on, and restores it onto another Apollo. Replacing the
  hardware no longer means setting everything up again: move the card across
  and tap **Restore from card**.

  The page says what the inserted card holds (when the backup was taken, and on
  which firmware and board), and a restore replaces every setting and restarts
  to apply it. Anything the backup doesn't carry returns to its default, so an
  older backup lands exactly as an upgrade would. Restoring between different
  boards works and is the point. A backup written by newer firmware than the
  machine you're restoring onto is refused — update it first.

  The file is plain text, so anyone with the card can read it. Your **WiFi
  network** and your **Micra pairing token** are each a switch on the backup
  confirmation: both on by default, because the point is a replacement that
  just works — turn one off and you set that up by hand on the new machine
  instead. Nothing is ever backed up or restored on its own.

## v0.14.0-beta.1

### Changes

- **Beta updates.** Settings > Apollo > WiFi has a new **Beta updates** switch
  (under "Check for updates"). With it on, Apollo also offers pre-release
  builds — versions like `0.14.0-beta.1` — so a release can be tried on real
  machines before it goes out to everyone. Everything else works the same: the
  notice shows what changed, **Install now** installs it, and a build that
  won't boot rolls back on its own. With the switch off you only ever see
  normal releases, which is still the default.

  Turning it off while running a beta doesn't move you back by itself — the
  device stays on that build until a normal release is newer than it. The
  [web flasher](https://mlsorensen.github.io/Apollo2/) has a matching **Include
  pre-releases** box for flashing one over USB.

- **The Dim idle screen keeps the screen on.** It now does what it did before
  the lion arrived: the backlight drops to the low level and the normal screen
  stays visible, so you can still read the machine's state from across the
  room. (It had been blanking the screen while leaving the backlight on, which
  gained nothing over Off.) The first touch still only wakes it. The dim level
  is set per board and will be tuned as each one is checked.

## v0.13.0

### Changes

- **The ESP32-P4-WIFI6-Touch-LCD-4.3 is supported again.** It's built,
  published and offered by the [web flasher](https://mlsorensen.github.io/Apollo2/)
  alongside the LCD-5, the S3-4.3C BOX and the X 8" box. It had been dropped in
  v0.12.2; if you're running one, updates work normally again from this release
  on. It is the **same board as the LCD-5** — same processor, radio, audio,
  battery, SD card and paddle wiring — with a 4.3" 800×480 screen instead of a
  5" 1280×720 one. Choose between the two on screen size and a small price
  difference; nothing else about them differs.
- **Finer control over the warm-up chime volume.** The four fixed levels (25 /
  50 / 75 / 100 %) are replaced by a slider with **–** and **+** buttons either
  side: drag to get close, tap to nudge 5 % at a time, and either way it plays a
  note at the new level so you can set it by ear. Just as importantly the scale
  is now even *to the ear* — before, everything above about 40 % sounded much
  the same and the quiet end jumped in big steps, because the setting was
  applied directly as signal strength rather than as loudness. **Your existing
  setting is carried over at the same volume**, so nothing changes how your
  machine sounds: if it was on 50 % it now reads 80 % and is exactly as loud as
  before.
- **Removed "Restart display" from Settings.** It was an escape hatch for the
  rare display glitch that was root-caused and fixed in v0.12.3, so there is
  nothing left for it to fix. The automatic re-alignment after every boot is
  unchanged.

## v0.12.3

### Fixes

- **The 4.3C's ghosted screen is fixed.** Since the first S3 boards, the
  display would occasionally latch into a corrupted state: roughly every tenth
  row flickering with content from the row band above, the picture sitting a
  few pixels high with the top wrapping to the bottom, sometimes from the
  moment it powered on, and only a restart or luck would clear it. The cause is
  a bookkeeping bug in the display driver Apollo is built on: whenever
  something holds up the panel's refill interrupt for more than half a
  millisecond (writing settings to flash is enough), the driver loses track of
  which of its two line buffers to fill next and never recovers. Apollo now
  corrects that every frame, so the same event costs one barely visible blip
  instead of a stuck screen. Verified on hardware both ways.
- **Settings > Restart display no longer reboots the 4.3C.** In v0.12.2 the
  button crashed the board instead of restarting the display (a side effect of
  the memory reclaim). It restarts the panel again, and with the fix above you
  should rarely need it.

- **The screensaver is fast again on the P4 boards.** v0.12.0 sped the
  bouncing lion up on the 4.3C but slowed it down on the P4-5 and the X boxes
  (about 12 fps at 93% CPU on the 5", from 30 fps at 75% before). The logo is
  now pre-rendered at each screen's own size, so every board draws it directly
  instead of scaling it — smoother on all of them, and the P4s are back above
  where v0.11 left them.

## v0.12.2

### Changes

- **Fixed the 4.3C gradually losing its network features.** On a machine with a
  scale paired and an SD card in, the remote could reach a state where checking
  for updates failed, the log page wouldn't load, and the WiFi/token setup portal
  would advertise but refuse to let a phone join it — all at once, and only
  clearing on a restart. The board had run out of a specific kind of internal
  memory that the radio, the display and encrypted connections all draw from.
  Apollo now uses roughly 26 KB less of it, which restores all three.
- **Fixed the "Check for updates" setting rendering in a smaller font** than the
  buttons above it in Settings > Device > WiFi.
- **The supported board line-up is now three boards.** Firmware images are
  built and published for the **ESP32-P4-WIFI6-Touch-LCD-5**, the
  **ESP32-S3-Touch-LCD-4.3C / 4.3C-BOX**, and the
  **ESP32-P4-WIFI6-Touch-LCD-X 8" box** — and those are what the
  [web flasher](https://mlsorensen.github.io/Apollo2/) offers. The P4-5 is the
  recommendation for mounting on the machine; the 4.3C is there for anyone who
  would rather not 3D-print a case or make up a paddle cable (it's the only
  supported board that's a finished box *and* has the opto-isolators built in);
  the X 8" is the counter-top companion.
- **Other boards are no longer published.** The S3 2", 4.3B and 7B, the bare
  P4 4.3, and the X 7" and 10.1" have been dropped from releases and from the
  web flasher. Nothing was removed from the source: every one of them still
  builds from this repo exactly as before, and their pin/panel definitions,
  build environments and printable shells are all still here. If you run one,
  **stay on v0.12.1 or build from source** — and note that your device will
  keep announcing new versions it cannot install, because the update check
  doesn't know which boards have published images. Declining the update, or
  turning the notices off under Settings > Apollo > WiFi, is the right move.
  A failed install is harmless: the device rolls back to the running firmware.
- **New printable backplate for the X 8" box**, so it mounts to the same
  counter-top stand as the other boards — see `hardware/3d-prints/`.

## v0.12.1

### Changes

- **Fixed "Check for updates" disappearing.** The button on Stats > Info and the
  **Check for updates** setting (Settings > Device > WiFi) would both vanish
  until the next restart, seemingly at random. They were being dropped whenever
  the screen layout rebuilt — which happens when you change the theme, or when a
  scale connects or disconnects. Automatic checks were still running the whole
  time; only the controls were missing.
- **The Micra's greyed-out "Connect" button is now a "Set up" button.** When a
  machine isn't paired yet, the button did nothing and didn't say what to do
  instead. Tapping it now takes you straight to Settings > Micra > Bluetooth. The
  status text is plainer too: **Not set up** (no machine chosen) and **Setup
  unfinished** (chosen, but pairing never completed) replace "Set up in Settings"
  and "Token needed".
- **Added a Dim option to the idle screen**, so there are now three: **Logo**
  (dimmed backlight with the bouncing lion), **Dim** (same dimmed backlight, but
  a plain black screen), and **Off** (backlight fully off). If you were using
  "Blank" before, you're now on "Off" — the same behaviour, clearer name.
- **Renamed two Display settings to match what they do.** "Screen dim" is now
  **Screen timeout** (it sets the idle time, not the brightness), and
  "Screensaver" is now **Idle screen**.
- **Added an Hourly update check** alongside Daily. Like Daily, it only runs
  while the machine is idle and the idle screen is up, so it never interrupts
  you.
- **The log page no longer freezes the display for as long.** Opening it showed
  the entire log, which locks the screen while it's sent. It now shows the most
  recent portion by default, with a link to the full log when you need it.
- **The machine keeps more log history.** Two messages were repeating far more
  than they needed to — the "no SD card" note and a line for every screen tap —
  which pushed older entries out. Quieting them means a problem from earlier in
  the day is more likely to still be recorded.

## v0.12.0

### Changes

- **Fixed the S3 boards falling off the network after every boot.** For about
  90 seconds after starting up, an S3 remote would get an IP address and then
  be unreachable — no clock sync, no update check, and the web page wouldn't
  load — before recovering on its own. The cause was the automatic update check
  starting before the network was actually usable: it then tied up memory the
  WiFi radio needed to receive anything, so it blocked the very connection it
  was waiting for. Apollo now waits for a confirmed internet clock sync before
  checking, so the check runs against a working connection and finishes in about
  a second. (This is what v0.11.4 was meant to fix; that change addressed a
  different theory and didn't solve it. The P4 boards were never affected.)
- **Fixed only the first update check of each session working.** After the check
  that runs at startup, every later check — including the daily one — was being
  refused for lack of memory, silently. The limit it was measured against was
  set too conservatively; it's now based on what a check actually uses.
- **Fixed the Logo screensaver going completely black on the 4.3C.** The dimmed
  backlight was being set below what that panel can show, so an idle machine
  looked switched off rather than asleep — and tapping it seemed to do nothing.
  The dim level is now set per board.
- **The screensaver is far smoother and uses much less power.** It was redrawing
  the shot graph hidden underneath it on every single frame. It now leaves the
  hidden graph alone, which makes the bouncing logo about four times faster and
  frees up processing for everything else. Shot recording is unaffected — a shot
  that starts while the screen is asleep is still captured in full.
- **Added a 1-minute option to Screen dim** (Settings > Display), alongside the
  existing 5, 15 and 30. A shot in progress never counts as idle, so the
  screensaver won't cover a live shot however short the timeout is; the countdown
  restarts when the shot finishes.

## v0.11.4

### Changes

- **Fixed unreliable WiFi on the S3 boards.** The S3's WiFi was going to sleep
  between beacons and dropping incoming packets even with a strong signal — which
  showed up as spotty connectivity, the clock rarely syncing over the internet,
  and "Check for updates" failing with "couldn't check". Apollo now keeps the
  S3's WiFi receiver awake while connected, so time sync and update checks work
  reliably. (The P4 boards were never affected.)

## v0.11.3

### Changes

- **More reliable clock sync, and you can see it.** After connecting to WiFi,
  Apollo now keeps retrying the time sync every ~30 s until it actually lands
  (instead of possibly waiting up to an hour on a missed first try), then settles
  to an hourly refresh. **Stats → Info** shows an honest **NTP synced** line —
  "2m ago", or "not since boot" if it hasn't synced yet — so you can tell at a
  glance whether the clock is really coming from the internet.

## v0.11.2

### Changes

- **Quieter, steadier update checks.** While the screensaver is on (machine
  idle), Apollo now pauses its Bluetooth reconnect attempts — no more pointless
  retrying when nobody's using the machine — and it runs the once-a-day update
  check in that idle window, when memory is freest, so the check is reliable and
  never gets in the way during use. An already-connected machine or scale stays
  connected. The startup check also stops retrying within about a minute so it
  can't linger.

## v0.11.1

### Changes

- **The update notice now tells you how to turn it off.** The "Update available"
  screen adds a line pointing to **Settings → Apollo → WiFi** (set **Check for
  updates** to **Off**) if you'd rather not be prompted.

## v0.11.0

### Changes

- **Apollo can update itself, right on the device.** With WiFi on, it checks
  the releases site and shows a notice when a newer firmware is out — with the
  version and release notes, and **Install now / Remind me later / Skip this
  version**. Install now downloads the new firmware and installs it: a progress
  bar, then a short "screen goes dark ~20 seconds, don't power off" phase, then
  it restarts on the new version. Your settings, paired machine and shot
  history are kept, and a firmware that won't boot rolls back on its own. The
  [web flasher](https://mlsorensen.github.io/Apollo2/) is still there for
  recovery and for the P4 boards' first flash.
- **Choose how it checks: Off / On boot / Daily.** Under **Settings → Apollo →
  WiFi → Check for updates**. "On boot" checks once each startup; "Daily" also
  re-checks about once a day while the machine stays on. You can always check
  by hand from **Stats → Info → Check for updates**; if it can't reach the
  server it says so instead of claiming you're up to date.
- **Steadier update checks.** A brief Wi-Fi/DNS hiccup during a check now
  retries instead of showing a spurious "couldn't reach the server" or a blank
  release-notes box.
- **Faster, more reliable Wi-Fi on the P4 boards.** On first boot Apollo
  updates the board's Wi-Fi co-processor to the matching firmware (a brief
  one-time "Updating Wi-Fi co-processor" screen), which fixes a stale-factory
  quirk that slowed every connection. One-time and automatic.
- **Settings → Device is now Settings → Apollo** — "Device" was ambiguous
  next to the machine and the scale; the page is about this device, Apollo.

## v0.10.0

### Changes

- **Screensaver enhanced** — the idle screen can now show a bouncing image
  over the dimmed display, or blank the screen entirely. Pick under
  **Settings → Device → Display → Screensaver** (Logo / Blank). **Screen
  dim** also gains a 5‑minute option.

- **X‑series 8" image fixed.** The previous 8" image was built for the older
  ESP32‑P4 silicon revision and could not boot the rev 3.0+ chips these boxes
  actually ship with (the board looked dead — no screen, no serial). The 8"
  image now targets rev 3.0+ silicon and mounts the picture the right way up
  for the 8" enclosure. (The 7" image is unchanged — 7" units in the wild are
  the older revision.)

## v0.9.0

### Changes

- **Two new boards: the Waveshare ESP32‑P4‑WIFI6‑Touch‑LCD‑X finished boxes
  (7" and 8").** All‑in‑one enclosed displays — no shell to print — with the
  same fast ESP32‑P4 internals as the 4.3/5, bigger screens (7" 1280×720,
  8" 1280×800), and the same optional Auto‑shot paddle wiring on GPIO 51/52.
  Each size takes its own image from the web flasher. The 7" is verified on
  hardware; the 8" is untested until one is on the bench.

- **Bookoo Themis Ultra works** — it speaks the same protocol as the Themis
  Mini and is recognized automatically (weight, tare, battery, beep and
  auto‑off). The **Beep** row on both scales now offers Off / 1–3, matching
  the Bookoo app: the out‑of‑range levels the wire accepts actually play
  *quieter* than level 3 (previously we offered 1–4).

- **Scan-to-set-up.** The token and Wi‑Fi setup screens now show a QR code:
  scan it with your phone's camera to join the `Micra-Setup` network, and the
  setup page opens by itself (the device now answers as a captive portal, like
  a hotel Wi‑Fi sign-in page). Joining manually and opening
  `http://192.168.4.1` still works exactly as before.

## v0.8.0

### Changes

- **Token setup is now always manual entry.** The old "read the token from the
  machine in pairing mode" path never actually worked on current machine
  firmware — that Bluetooth characteristic holds a pairing *seed*, not a readable
  token — so it has been removed. After you pick your machine, enter its token
  (get it with the **LM Token** app) over the `Micra-Setup` Wi‑Fi page. Existing
  tokens and settings are untouched.

### Fixes

- **`Micra-Setup` Wi‑Fi wouldn't accept connections while on your home Wi‑Fi.**
  Opening the token / Wi‑Fi setup page while the device was connected (and serving
  the History web app) left the `Micra-Setup` network visible but impossible to
  join. The device now cleanly drops the home connection before starting the
  access point, and reconnects when the setup page closes.
- **Switching shot mode now cancels an in-progress shot.** Changing the shot mode
  (Manual / Auto shot / Shot detect) while a shot timer is running resets it to
  idle and drops the drive line, so a timer can't be left ticking under the wrong
  mode.

### Features

- **"Machine is in pairing mode" prompt.** If the machine is left in
  configuration/pairing mode, the device now tells you to restart it instead of
  silently looping on a failed connection.

## v0.7.1

### Fixes

- **Spontaneous reboot on SD‑card hiccups (P4 boards).** A mount retry or an
  unmounted/removed SD card could — after enough cycles — tear down the SDMMC
  peripheral the WiFi/BLE co‑processor shares (an IDF slot‑refcount
  over‑decrement), crashing the radio and rebooting the device. Diagnosed
  from a captured coredump; the SD driver can no longer deinitialize the
  shared host under any circumstances.
- **Nuisance ready chimes.** The warm‑up chime now sounds at most **once per
  turn‑on**. Heavy steaming, refills, or steam‑boiler toggles no longer
  re‑arm it mid‑session; standby/off/disconnect still does, so the next
  warm‑up chimes as before.

### Features

- **Crash dumps are downloadable.** If the firmware crashes, the automatic
  post‑mortem snapshot it saves to flash is now surfaced: the boot log says
  `crash dump stored`, and a **Crash dump** link appears on the web page
  (`http://⟨device IP⟩/coredump`; `?erase=1` clears it) to download it as a
  file to attach to a bug report. The filename is a fingerprint of the build
  that crashed — correct even if the device was upgraded since — and each
  release now ships a debug‑symbols archive whose `.appsha` files match
  fingerprints to the right decoding `.elf`.

## v0.7.0

### Features

- **Scale device settings.** Settings stored on the scale itself — beep,
  auto-off, and more — are now adjustable from the remote, on a new
  **Settings → Scale → Device settings** page. The rows adapt to the
  connected scale:
  - **Bookoo Themis** — beep level (Off / 1–4) and auto-off (5–30 min).
  - **Acaia Umbra** — beep on/off and auto-sleep timer, plus **Unit**
    (g / oz).
  - **Acaia Lunar / Pyxis** — beep toggle (the row shows the volume stored
    on the scale), auto-sleep, **Unit** (g / oz), and the current weighing
    mode (shown for reference — Acaia's protocol can't change modes
    remotely).
  - Rows show the scale's live values while connected, with a **Connect**
    shortcut right on the page when it isn't. Switching an Acaia to ounces
    only changes the scale's own display: Apollo keeps working in grams, so
    brew-by-weight targets stay correct.
  - The old Scale → Settings page split into **Shot settings** and
    **Device settings**, so neither page needs scrolling.
- **Varia Aku support.** The Aku (Micro/Mini/Pro) joins Bookoo and Acaia as
  a supported scale: live weight, tare, and a battery readout — including
  its battery frames, which aren't in any public protocol documentation.
  Its gauge reports in 20% steps, so the battery icon turns red at its
  final step before empty (each scale model now sets its own low-battery
  threshold).

### Fixes

- **Tare and Disconnect lock during a shot.** Both scale-card buttons (and
  the new device-settings rows) disable while a shot is running or
  settling — a mid-shot tare would corrupt the auto-stop math — and
  re-enable the moment the shot ends, however it ends.
- **Scale settings changes stick.** Acaia scales silently drop Bluetooth
  writes that arrive in quick bursts; setting changes are now paced the way
  Acaia's own app paces them, confirmed against the scale's reported state,
  and retried when the scale ignores one.
- **Scale scanning is more reliable.** The scan window doubled to 10
  seconds — scales that advertise infrequently (the Aku) could slip through
  the old window while the radio was also servicing the Micra connection.

## v0.6.2

### Features

- **A choice of ready chimes.** New **Chime melody** setting
  (**Settings → Micra → Controls**) with a handful of tunes to choose from —
  tap to cycle through them and hear each one — plus a **Random** option
  that plays a different tune each time the machine finishes warming up.
  The existing Chime volume setting keeps controlling the level, and `Off`
  is right there in the cycle.

## v0.6.1

### Fixes

- **The power button acknowledges the tap instantly.** The Micra reports a
  mode change a couple of seconds after the command, so tapping
  `Standby`/`Turn on` looked like nothing happened — and invited a second,
  state-undoing tap. The button now immediately disables and reads
  `Working...` until the machine reports the change (or the link drops, or
  8 seconds pass — it can never stay locked).

## v0.6.0

### Features

- **Shot detect shows the real shot the moment it's detected.** Detection
  confirms a few seconds after the first drip; until now the screen kept the
  generic live graph and the raw scale weight (cup included) for the whole
  shot, and only the end-of-shot review showed the aligned picture. Now, the
  instant a shot is detected, the graph switches to the shot plot back-filled
  from history — the ramp you already poured, from the estimated start — and
  the weight readout drops to shot grams, matching what a wired shot shows.
- **No more accidental untracked shots.** In Auto shot and Shot detect modes,
  flipping the paddle while no scale is connected now leaves the machine off
  and shows a message ("connect the scale or switch to Manual mode") instead
  of silently running a shot with no timing, tracking, or auto-stop. Waking a
  standby machine with a paddle flip is unaffected, and Manual mode plus the
  Flush button still cover deliberate untracked runs.
- **Four new themes matching the Micra body colors.** Like the existing
  Ferrari theme for the red machine, each runs its machine's paint through
  the whole scheme: **Modena** (yellow), **Gulf** (light blue, with the
  livery's orange as the heating color), **Monaco** (navy), and **Ivory**
  (creme). Settings → Device → Display → Theme.
- **The ready chime carries better.** The warm-up chime is now the "Buddy
  Holly" intro riff — all of it above 650 Hz, where the small speaker actually
  has output; the old arpeggio's low notes faded a room away.
- **New "Detect lead-in" setting** (**Settings → Scale → Settings**, 0–10 s,
  default 3 s): how far before the first drip your shot actually starts —
  the paddle flip, then preinfusion water working through the puck. It's
  added when back-dating a detected shot, so the timer and graph line up
  with the moment you flipped the paddle. Adjust it to match your machine's
  preinfusion setting as needed; detected shot durations now include it.

## v0.5.3

### Features

- **A diagnostic log you can read after the fact.** The device now keeps its
  recent diagnostics (the same messages the USB serial console prints, plus
  the system's own) in memory — 64 KB, typically hours of normal use — with
  each line stamped with the time, or seconds-since-boot until the clock is
  set. Read it on the device (**Stats → Info → Diagnostic log**) or, with
  Wi-Fi connected, as plain text at `http://<device IP>/log` (the web page's
  header has a **Log** link too). So when the paddle "did nothing" this
  morning, the evidence is still there after breakfast — no serial cable at
  the moment of failure required. The log doesn't survive a reboot.

### Fixes

- **The standby/turn-on button reflects the machine's state faster.** The
  Micra's Bluetooth interface answers state queries with a lag right after a
  mode change, so the old "read back immediately after the command" approach
  reliably saw the previous state and the screen then waited out a slow 3 s
  poll — occasionally 4 s of nothing after a tap. The state poll now simply
  runs every second, so the button settles within about a second of the
  machine actually switching.

## v0.5.2

### Fixes

- **Upgrading with the web flasher no longer wipes your settings.** Installing
  a new version cleared the paired machine, the Wi-Fi credentials and every
  setting — even when "Erase device" was left unchecked — and there was no way
  to avoid it. The published image was a single blob covering the whole start
  of the flash, and the unused space it padded along the way happened to be the
  partition those settings live in, so writing it scrubbed them every time. The
  flasher now installs the same firmware in pieces that step around that
  partition, so an upgrade keeps everything and a deliberate "Erase device"
  still starts you clean. Flashing the attached `.bin` by hand with `esptool`
  is still a full image, and still clears settings — that's what it's for.

## v0.5.1

### Features

- **History shows how each shot was run.** Every recorded shot now carries a
  tag — a bolt for an **Auto** shot (the wired paddle stopped it at weight) or
  an eye for a **Detect**ed one (inferred from the scale alone) — in its own
  column in the shot list, on the shot card, and in the web app's table. Useful
  when you switch modes: an auto shot that missed its target and a detected one
  that was never going to stop at all are different stories, and the list used
  to tell them identically. Nothing to enable, and it applies to shots you have
  already recorded — the mode was being saved to the SD card all along, it just
  wasn't shown in the list.

### Fixes

- **The web page can no longer lag behind the firmware it ships with.** The
  History page a board serves was baked in from a pre-built file kept in the
  repo, so it was only ever as current as the last time someone remembered to
  regenerate it by hand — a page could go out with an older version of itself
  than the firmware around it. It is now rebuilt from source as part of every
  firmware build and every release, so what you flash is what you get.

## v0.5.0

### Features

- **The machine chimes when it's up to temperature** *(boards with a speaker —
  the 4.3C and the P4s)*. Switch it on, walk away, and a short rising chime
  tells you it's ready. It marks the *end of a warm-up*, so it sounds **once**
  and then stays quiet through all the small dips and reheats that hold
  temperature. It re-arms when a new warm-up is genuinely coming: the machine
  goes to standby (or off, or disconnects), the steam boiler is switched on or
  off, or a boiler falls 10 °C below its set point. With the steam boiler off
  the chime follows the coffee boiler alone; with it on, both have to be there.
  - **Settings → Micra → Controls → Chime volume** — Off / 25 / 50 / 75 / 100 %,
    default 50 %. Each tap plays a note at the new level, so you can set it by
    ear.

### Improvements

- **Settings → Micra → Settings is now Settings → Micra → Controls** — a
  "Settings" page inside Settings read poorly, and the page is the machine's
  controls: brew temperature, steam boiler, wired paddle.
- **Auto connect moved to Settings → Micra → Bluetooth**, next to the saved
  machine it applies to, where a scan can no longer push it off the screen.

### Fixes

- **"Ready" is recognised properly again.** The machine's own thermostat works
  to about 2 °C — a steam boiler set to 128 °C routinely settles at 127 °C and
  stops heating there — but the display insisted on 0.75 °C and so could show
  **Heating** indefinitely on a machine that was long since ready. Anything
  within 2 °C of the set point now counts as ready. (This is also what the new
  chime waits for, so on affected machines it would never have fired at all.)
- **Opening a shot in the web app is fast** — a fraction of a second instead of
  seven or eight, on the same data.
- **Loading the web page no longer starves the device.** Serving it briefly
  consumed most of the free internal memory, which showed up as display
  glitches and dropped Bluetooth traffic while a page was open.
- **The display stops falling back to slow software copies** on the P4 5" while
  Wi-Fi and Bluetooth are busy, so the interface keeps its frame rate during a
  web page load.
- **A Micra sitting connected in standby no longer floods the serial log**, which
  was costing enough time per frame to visibly stall the interface.

## v0.4.1

A bug-fix release — no new features.

### Fixes

- **Acaia scales no longer get stuck "connected" with no weight.** A link could
  sit connected and acking, and never deliver a reading. Several separate
  causes: liveness was judged on any Bluetooth traffic (which a scale keeps
  sending even when its weight events were never registered), the event
  registration itself was subtly malformed, incoming frames were mis-parsed the
  moment a fixed-length one arrived, and the handshake could be written before
  the scale was ready to hear it. The link now watches the *weight* stream
  specifically, re-handshakes when it stalls, and reconnects if it stays silent.
  Connecting is also faster to first reading.
- **Acaia weights could read 100× high** on scales that report their decimal
  place as 0.
- **The graph smoothing setting now affects the live graph**, not just the
  frozen shot review. Previously the sweep you watch while pulling a shot
  stayed unsmoothed at every setting. *Strong* is now a wider filter than
  before; Off, Light and Medium behave as they did.
- **Shots freeze for review when the drips actually stop**, instead of after a
  fixed 3 seconds — so the final weight is a settled one. This also makes the
  learned overshoot compensation more accurate, since that's the number it
  grades itself against.
- **The stop hint (unwired mode) learns its own timing.** It shares nothing
  with the wired auto-stop now, because it also has to cover your reaction time
  between seeing the hint and flipping the paddle; one shared value had the two
  modes pulling against each other on a wired machine.
- **The 2-inch board no longer fails to start with "display init failed"** — it
  was the only board taking its drawing buffer from the same scarce internal
  memory that Wi-Fi and Bluetooth need, and the request had grown too large to
  fit.
- **An empty SD slot no longer floods the serial log.** Boards without a card
  were logging a mount failure every 5 seconds, burying everything else.

## v0.4.0

### Features

- **Backflush cleaning** *(boards with the paddle harness)* — a guided,
  full-screen cleaning mode under **Settings → Micra → Cleaning**. Fit the
  blind filter, tap **Go**, and the device pulses the group 10 times with a
  live cycle counter and countdown. **Cancel** stops it and stays put,
  **Back** stops it and leaves, and flipping the physical paddle stops it too.
  - Pulse length follows your **Auto flush** setting. If your machine
    preinfuses, note that every pulse restarts preinfusion — set Auto flush
    long enough that each pulse outlasts it, or turn preinfusion off while
    backflushing.
- **Flush button on Home** *(paddle boards, 4.3" and larger)* — the Micra
  card's single button is now **Standby | Flush**, mirroring the scale card's
  Disconnect | Tare. Flush runs the group for a quick rinse; tap again to stop
  early.
- **Delete individual shots** — open a shot from **Stats → History** and tap
  the trash button. The shot is removed from the SD card and the headline
  stats recalculate without it, so dial-in and practice shots no longer skew
  your accuracy numbers.
- **Auto flush is now Off / 3 / 6 / 9 / 15 s** (was Off / 3 / 6). This single
  duration drives every timed run of the group: the post-shot auto-flush, the
  new Flush button, and each backflush pulse.

### Improvements

- **Settings → Device is split into Display, Time & date, and WiFi.** The old
  single page had grown long enough that reading it meant scrolling past most
  of it; each sub-page now fits on screen.
- **Setting the clock is faster** — Time (hour, minute) and Date (month, day,
  year) are now dropdown pickers on one row each, replacing six separate
  −/+ rows. **Timezone** moved here from the WiFi page, where it never really
  belonged: it governs how every time is displayed, not just NTP.
- **Flush settings live with cleaning** — Auto flush and Flush delay moved to
  the new **Micra → Cleaning** page alongside Backflush, which also shortens
  the Micra settings page.
- **The Micra button on Home shows the action, not the state.** It reads
  Standby / Turn On / Connect and is simply disabled when unavailable; the
  connection state was already spelled out in the card's status line, and the
  old wording no longer fit beside Flush.
- The manual now says what it should about storage: **a small SD card is more
  than enough.** A shot is a few tens of KB, so even a 1 GB card holds years
  of espresso — and small cards are usually already FAT32.

## v0.3.0

- Full shot history: every finished shot is recorded to the SD card as plain
  CSV under `/Apollo2`, with an on-device History view (totals, lifetime and
  30-day accuracy, month filter, per-shot cards) and a built-in web page for
  browsing and downloading from a phone or computer.
- Fixed the RGB panel's ghosted/shifted raster on the S3 4.3C.
- Expanded the manual: SD formatting (FAT32 only), hot-swap behavior, the
  on-card data layout.

## v0.2.0

- Three-way shot mode: Auto shot / Shot detect / Manual, so wired rigs can use
  the weight-stream detector too.
- Auto-flush delay became a setting (3 / 6 / 9 / 15 s).
- Fixed Bluetooth scan contention — scanning while the other device was
  connecting used to fail outright.
- Five new themes (Mono, Contrast, Ferrari, Sunset, Citrus), 3D-printable case
  and stand files, and the first version of the user manual.

## v0.1.1

- Wrong-board protection in the web flasher: the firmware answers a serial
  identify query, so the page detects and auto-selects the right board.

## v0.1.0

- First public release: brew-by-weight with paddle control, unwired shot
  detection, scale support (Bookoo Themis, Acaia Umbra / Lunar), temperature
  history, and the web flasher.

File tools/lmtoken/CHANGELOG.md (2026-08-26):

# lmtoken changelog

Notes for each `lmtoken-vX.Y.Z` release. The release workflow extracts the
section whose heading matches the tag (minus the `lmtoken-` prefix, e.g.
`## v0.2.1`) and appends the standard download/install boilerplate. Keep the
section for a version complete before tagging it.

## v0.2.1

- Fixed: when the machine derives a new token but saving it to your La Marzocco
  account fails, the token is now handed to you anyway (with a warning) instead
  of being discarded. The machine starts using that token the moment it's
  written, so you need it even if the account save didn't go through — your
  remote connects with it; your La Marzocco app may just need re-syncing. Both
  the app and the CLI now surface it.

## v0.2.0

- Set up a Bluetooth token when the cloud has none: sign in, and if your machine
  has no token, lmtoken can provision one over Bluetooth (put the machine in
  pairing mode and follow the prompts) — in both the app and the CLI.
- Cross-platform: macOS, Linux, and Windows, for both the app and the CLI.
- `-force` re-mints a fresh token even if one already exists; `-debug` prints
  raw server responses and Bluetooth diagnostics; `-scan` lists nearby
  Bluetooth devices to confirm your machine is visible.
- macOS app and CLI are signed and notarized.

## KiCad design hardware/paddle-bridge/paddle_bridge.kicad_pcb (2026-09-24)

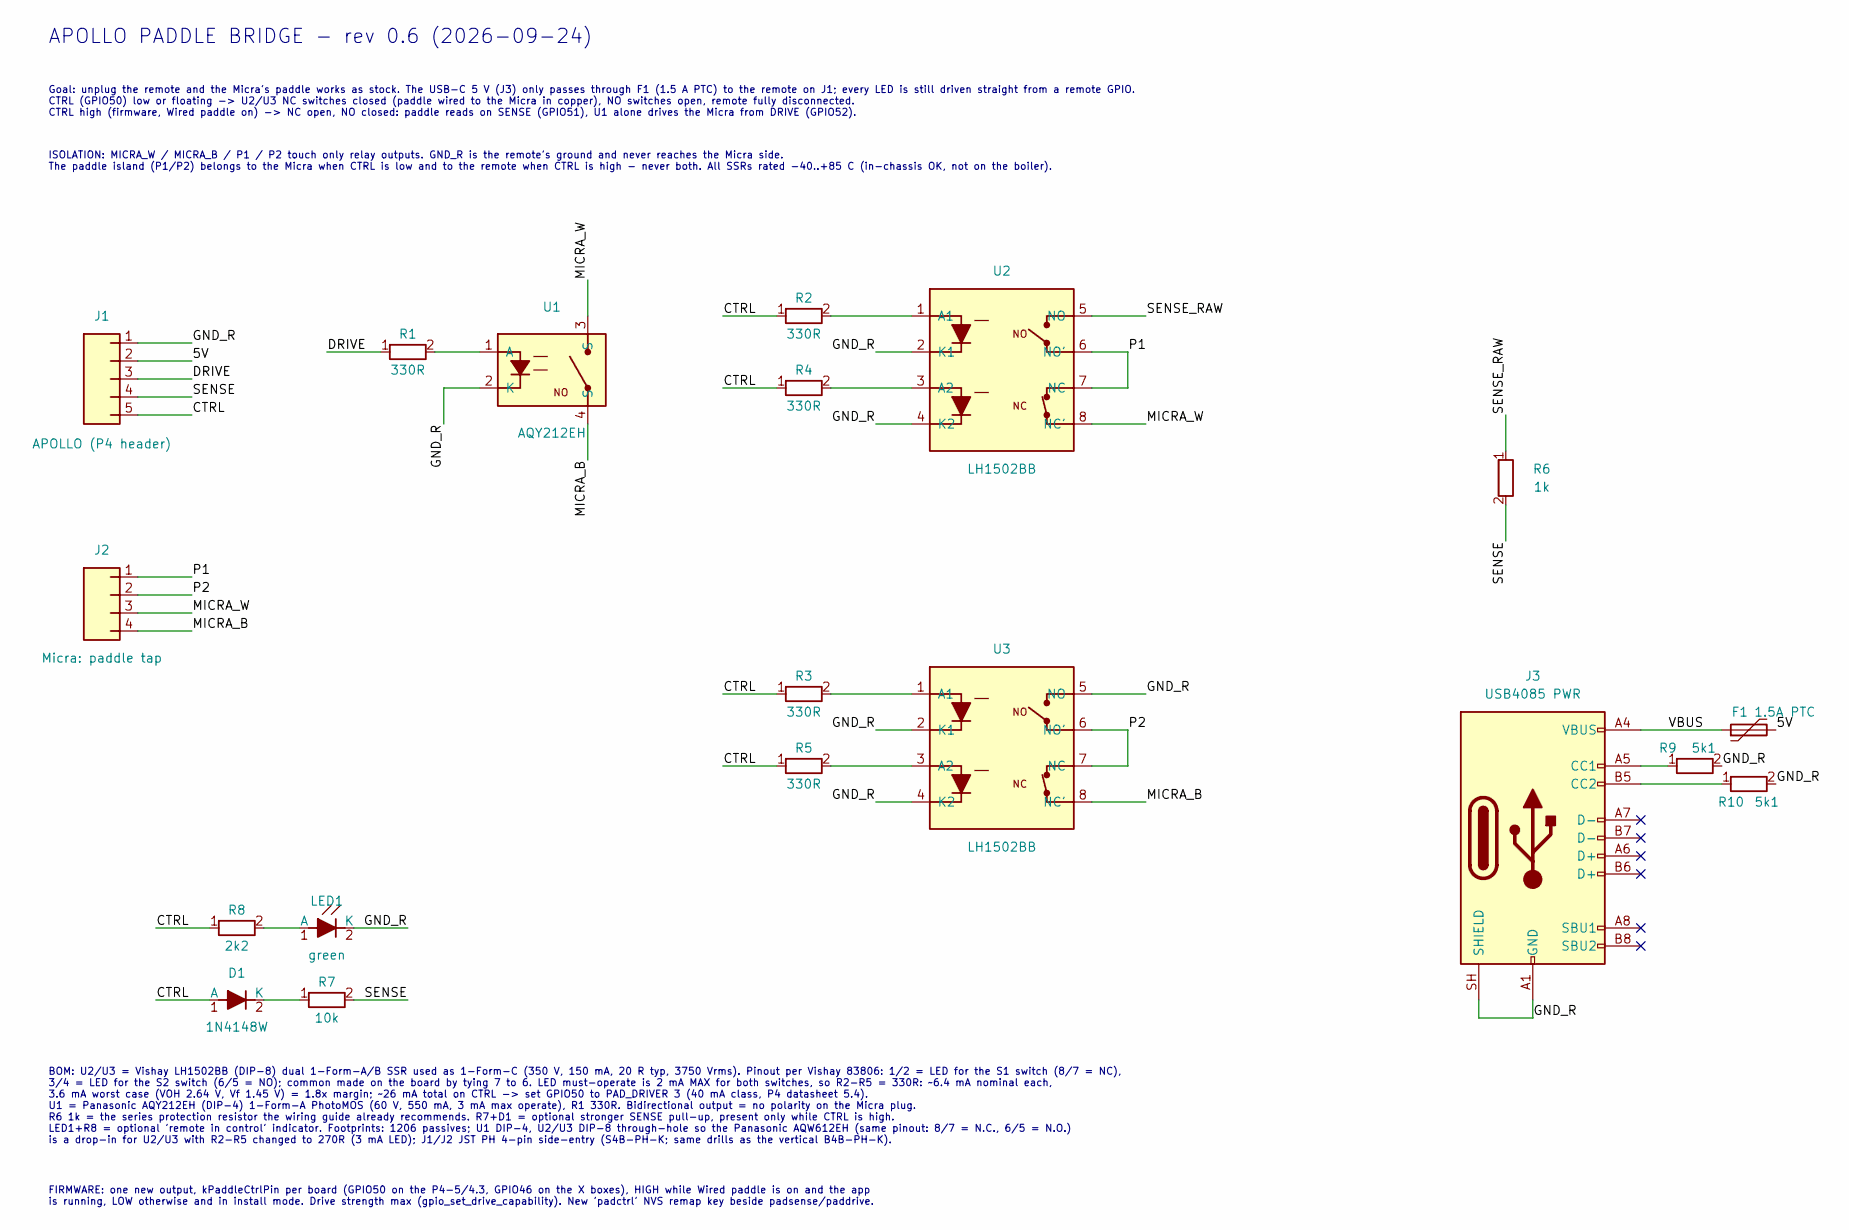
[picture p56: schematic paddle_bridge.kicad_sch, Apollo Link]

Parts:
D1: 1N4148W; D_1206_3216Metric
F1: 1.5A PTC; Fuse_1812_4532Metric
J1: APOLLO (P4 header); JST_PH_S5B-PH-K_1x05_P2.00mm_Horizontal
J2: Micra: paddle tap; JST_PH_S4B-PH-K_1x04_P2.00mm_Horizontal
J3: USB4085 PWR; USB_C_Receptacle_GCT_USB4085
LED1: green; LED_1206_3216Metric
R1, R2, R3, R4, R5: 330R; R_1206_3216Metric
R6: 1k; R_1206_3216Metric
R7: 10k; R_1206_3216Metric
R8: 2k2; R_1206_3216Metric
R9, R10: 5k1; R_1206_3216Metric
U1: AQY212EH; DIP-4_W7.62mm
U2, U3: LH1502BB; DIP-8_W7.62mm

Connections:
/5V: F1.2, J1.2
/CTRL: D1.1 (A), J1.5, R2.1, R3.1, R4.1, R5.1, R8.1
/DRIVE: J1.3, R1.1
/GND_R: J1.1, J3.A1 (GND), J3.A12 (GND), J3.B1 (GND), J3.B12 (GND), J3.SH (SHIELD), LED1.2 (K), R9.2, R10.2, U1.2 (K), U2.2 (K1), U2.4 (K2), U3.2 (K1), U3.4 (K2), U3.5 (NO)
/MICRA_B: J2.4, U1.4 (S), U3.8 (NC')
/MICRA_W: J2.3, U1.3 (S), U2.8 (NC')
/P1: J2.1, U2.6 (NO'), U2.7 (NC)
/P2: J2.2, U3.6 (NO'), U3.7 (NC)
/SENSE: J1.4, R6.2, R7.2
/SENSE_RAW: R6.1, U2.5 (NO)
/VBUS: F1.1, J3.A4 (VBUS), J3.A9 (VBUS), J3.B4 (VBUS), J3.B9 (VBUS)
unnamed: D1.2 (K), R7.1
unnamed: J3.A5 (CC1), R9.1
unnamed: J3.B5 (CC2), R10.1
unnamed: LED1.1 (A), R8.2
unnamed: R1.2, U1.1 (A)
unnamed: R2.2, U2.1 (A1)
unnamed: R4.2, U2.3 (A2)
unnamed: R3.2, U3.1 (A1)
unnamed: R5.2, U3.3 (A2)

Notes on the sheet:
Goal: unplug the remote and the Micra's paddle works as stock. The USB-C 5 V (J3) only passes through F1 (1.5 A PTC) to the remote on J1; every LED is still driven straight from a remote GPIO. CTRL (GPIO50) low or floating -> U2/U3 NC switches closed (paddle wired to the Micra in copper), NO switch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
BOM: U2/U3 = Vishay LH1502BB (DIP-8) dual 1-Form-A/B SSR used as 1-Form-C (350 V, 150 mA, 20 R typ, 3750 Vrms). Pinout per Vishay 83806: 1/2 = LED for the S1 switch (8/7 = NC), 3/4 = LED for the S2 switch (6/5 = NO); common made on the board by tying 7 to 6. LED must-operate is 2 mA MAX for both sw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
APOLLO PADDLE BRIDGE - rev 0.6 (2026-09-24)
FIRMWARE: one new output, kPaddleCtrlPin per board (GPIO50 on the P4-5/4.3, GPIO46 on the X boxes), HIGH while Wired paddle is on and the app is running, LOW otherwise and in install mode. Drive strength max (gpio_set_drive_capability). New 'padctrl' NVS remap key beside padsense/paddrive.
ISOLATION: MICRA_W / MICRA_B / P1 / P2 touch only relay outputs. GND_R is the remote's ground and never reaches the Micra side. The paddle island (P1/P2) belongs to the Micra when CTRL is low and to the remote when CTRL is high - never both. All SSRs rated -40..+85 C (in-chassis OK, not on the boil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

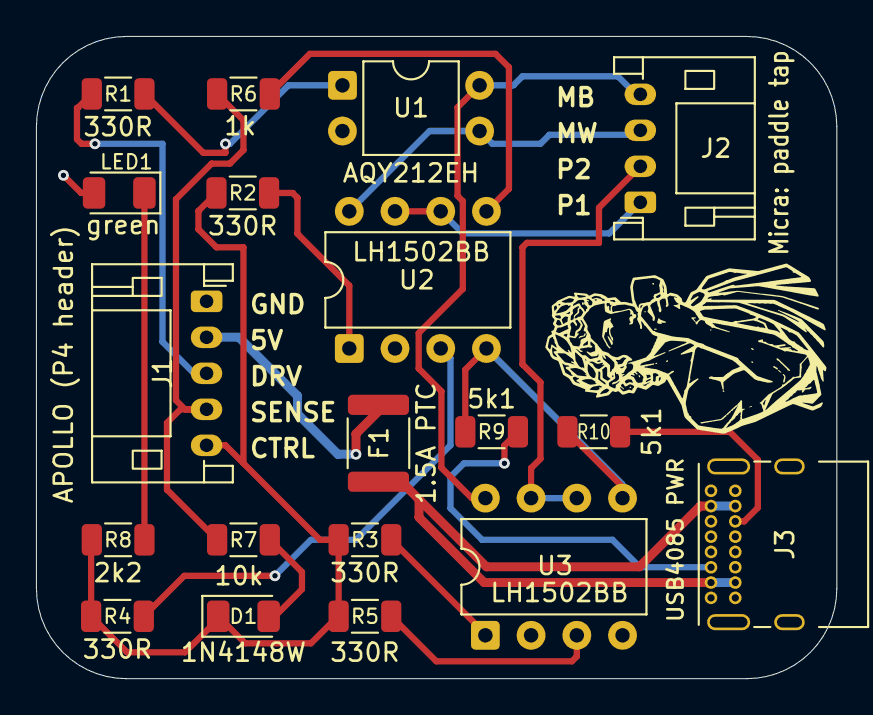
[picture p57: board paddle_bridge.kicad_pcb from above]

Board: 2 copper layers, 44.5 x 35.7 mm, 19 parts (0 on the bottom side), 20 nets.

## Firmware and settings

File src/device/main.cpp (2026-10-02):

#include <Arduino.h>
#include <NimBLEDevice.h>

#include <cstdlib>
#include <cstring>
#include <Wire.h>
#if defined(CONFIG_ESP_HOSTED_ENABLE_BT_NIMBLE)
#include <esp32-hal-hosted.h>  // hostedInitBLE(): SDIO link to the radio co-processor
#endif
#include <esp_sleep.h>
#include <soc/soc_caps.h>
#if SOC_PM_SUPPORT_EXT0_WAKEUP
#include <driver/rtc_io.h>
#endif
#include <lvgl.h>

#include <esp_heap_caps.h>
#include <esp_ota_ops.h>
#include <hal/efuse_hal.h>
#if __has_include(<esp_core_dump.h>)
#include <esp_core_dump.h>
#endif

#include "core/brew_controller.h"
#include "core/log_ring.h"
#include "core/system.h"
#include "platform_esp32/battery.h"
#include "platform_esp32/board_config.h"
#include "platform_esp32/c6_update.h"
#include "platform_esp32/clock.h"
#include "platform_esp32/config.h"
#include "platform_esp32/crash_record.h"
#include "platform_esp32/display.h"
#include "platform_esp32/display_settings.h"
#include "platform_esp32/schedule_settings.h"
#include "platform_esp32/history.h"
#include "platform_esp32/install_mode.h"
#include "platform_esp32/io_extension.h"
#include "platform_esp32/log_setup.h"
#include "platform_esp32/micra_link.h"
#include "platform_esp32/network.h"
#include "platform_esp32/update_check.h"
#include "platform_esp32/paddle.h"
#include "platform_esp32/provisioner.h"
#include "platform_esp32/scale_link.h"
#include "platform_esp32/shot_store.h"
#include "platform_esp32/sound.h"
#include "platform_esp32/scale_provisioner.h"
#include "platform_esp32/token_setup.h"
#include "platform_esp32/touch.h"
#include "platform_esp32/web_ui.h"
#include "ui/app.h"
#include "ui/theme.h"
#include "version.h"

// Device entry. Brings up the panel + touch, builds the UI bound to the BLE
// machine, and starts MicraLink's background connection task. The main loop only
// runs LVGL and periodically refreshes the UI from MicraLink's cached snapshot —
// all BLE I/O (connect, poll, reconnect) happens off-thread, so the UI stays
// responsive whether the machine is connected, connecting, or offline.

namespace {

platform::Display g_display;
platform::Touch g_touch;
platform::Config g_config;
platform::MicraLink g_micra;
platform::TokenSetup g_token_setup{g_config, g_micra};
platform::Provisioner g_provisioner{g_micra, g_config, g_token_setup};
platform::Battery g_battery;
platform::DisplaySettings g_display_settings{g_display, g_config};
platform::ScheduleSettings g_schedule{g_config};  // Settings > Micra > Schedule (NVS)
platform::Clock g_clock{g_config};
platform::Network g_network{g_config, g_clock, g_token_setup};  // WiFi station + NTP
platform::UpdateCheck g_update_check{g_config, g_network};  // daily release check
platform::History g_history;
platform::ScaleLink g_scale;            // NimBLE Bluetooth scale (Bookoo/Acaia)
platform::ScaleProvisioner g_scale_provisioner{g_scale, g_config};
// Brew-by-weight: paddle relay + shot state machine over the paddle + scale
// ports (core logic; polled from loop()).
core::BrewController g_brew{platform::paddle(), g_scale};
// Shot history: SD-backed on boards with a card slot; NullShotStore elsewhere
// (the History tab shows guidance instead).
#if defined(BOARD_HAS_SD_MMC)
platform::ShotStore g_shots;
#else
core::NullShotStore g_shots;
#endif
platform::WebUi g_web_ui;  // the ONE HTTP server (setup portal + history app)
ui::App g_app;

constexpr uint32_t kUiRefreshMs = 500;
constexpr uint32_t kSampleMs =
    platform::History::kSampleIntervalS * 1000;  // temperature history cadence

// Survives deep sleep (cleared only on a cold boot / power loss): set when we park
// for low battery so the next wake does the dark battery check in setup() before
// powering anything up.
RTC_DATA_ATTR uint32_t g_lowbatt_sleep = 0;

// Deep sleep until a screen touch (or external reset). True power-down (~uA) — no
// timer poll. The touch controller's INT line (idles high, pulls low on touch) is
// the wake source where it's on an RTC GPIO; the 2-inch has no INT wired
// (kTouchInt < 0), so there it wakes only on reset.
void enter_lowbatt_sleep() {
  g_lowbatt_sleep = 1;
  if (board::kTouchInt >= 0) {
    const auto pin = static_cast<gpio_num_t>(board::kTouchInt);
#if SOC_PM_SUPPORT_EXT0_WAKEUP
    rtc_gpio_pullup_en(pin);
    rtc_gpio_pulldown_dis(pin);
    esp_sleep_enable_ext0_wakeup(pin, 0);  // wake when INT goes low (a touch)
#elif SOC_PM_SUPPORT_EXT1_WAKEUP
    // Chips without EXT0 (e.g. the P4): EXT1 with a one-pin mask, wake on low.
    esp_sleep_enable_ext1_wakeup(1ULL << pin, ESP_EXT1_WAKEUP_ANY_LOW);
#endif
  }
  esp_deep_sleep_start();  // never returns
}

// Minimal init to read the pack WITHOUT lighting the screen (the dark check on a
// low-battery wake). The 2-inch reads a direct ADC (no init); the 7B reads via the
// I2C IO-extension, so bring that up but force the backlight off.
void batt_only_init() {
#if defined(BOARD_HAS_IO_EXTENSION)
  Wire.begin(board::kI2cSda, board::kI2cScl);
  platform::io_extension().begin(board::kIoExtAddr);
  platform::io_extension().set(board::kIoExtBacklight, false);
#endif
}

}  // namespace

// Arduino weak-hook override: do NOT auto-confirm an OTA-installed image at
// init — loop() confirms it after 60 s of healthy running (above), so a build
// that boots but immediately crashes still rolls back.
extern "C" bool verifyRollbackLater() { return true; }

void setup() {
  Serial.begin(115200);
#if defined(ARDUINO_USB_CDC_ON_BOOT) && ARDUINO_USB_CDC_ON_BOOT
  // Native USB-CDC: with no serial host attached, writes otherwise BLOCK on a TX
  // timeout until the buffer drains — which stalls the main loop (and thus touch/
  // rendering) whenever anything logs. 0 = never block (drop if no reader). This
  // is why the UI felt sluggish until a serial monitor was connected. (Boards on
  // a real UART bridge — e.g. the P4 — don't have or need this.)
  Serial.setTxTimeoutMs(0);
#endif

  // Woke from a low-battery park (a touch or a reset)? Read the pack WITHOUT
  // powering up the panel/LVGL/BLE and REFUSE to fully boot unless it has charged
  // past the resume threshold (hysteresis above the cutoff, so the at-rest voltage
  // rebound doesn't count) — otherwise go straight back to sleep. This avoids a
  // half-up, backlight-off zombie that would only brown out again; the device
  // stays dark until there's genuinely enough power to run.
  if (g_lowbatt_sleep) {
    batt_only_init();
    const core::BatteryState b = g_battery.battery();
    // On USB (node at/above the USB threshold) or rested past the resume level
    // -> boot. A pack still charging below the resume level stays parked; it'll
    // pass the threshold as it charges.
    if (!(b.usb || b.volts >= board::kBatteryResumeVolts)) enter_lowbatt_sleep();
    g_lowbatt_sleep = 0;  // charged enough -> fall through to a normal boot
  }

  // Log ring before the first diagnostic, so the banner onward is replayable
  // from Stats > Info or http://<ip>/log after the fact.
  platform::log_init();
  platform::crash_record::install();  // failed-allocation flight recorder

  delay(300);  // let USB-CDC enumerate
  core::logf("\n");
  core::logf("Micra remote — %s\n", board::kName);
  {
    // Why did we boot? Distinguishes power-rail dips (BROWNOUT/POWERON — e.g.
    // the USB<->battery switchover glitch on the P4 4.3) from firmware faults.
    const esp_reset_reason_t rr = esp_reset_reason();
    const char* name = "other";
    switch (rr) {
      case ESP_RST_POWERON:   name = "power-on"; break;
      case ESP_RST_SW:        name = "software"; break;
      case ESP_RST_PANIC:     name = "panic"; break;
      case ESP_RST_INT_WDT:
      case ESP_RST_TASK_WDT:
      case ESP_RST_WDT:       name = "watchdog"; break;
      case ESP_RST_BROWNOUT:  name = "brownout"; break;
      case ESP_RST_DEEPSLEEP: name = "deep-sleep wake"; break;
      case ESP_RST_USB:       name = "usb"; break;
      default: break;
    }
    core::logf("reset reason: %s (%d)\n", name, static_cast<int>(rr));
  }
  {
    // Which OTA slot is live, and is it awaiting its health confirm?
    const esp_partition_t* run = esp_ota_get_running_partition();
    esp_ota_img_states_t st;
    const bool pending = esp_ota_get_state_partition(run, &st) == ESP_OK &&
                         st == ESP_OTA_IMG_PENDING_VERIFY;
    core::logf("OTA: running from %s%s\n", run != nullptr ? run->label : "?",
               pending ? " (pending verify - confirms after 60s)" : "");
  }
#if defined(CONFIG_ESP_COREDUMP_ENABLE_TO_FLASH)
  {
    // A panic/watchdog reset leaves an ELF coredump in the `coredump` flash
    // partition. Announce it so /log readers know a downloadable post-mortem
    // exists; it persists (across reboots AND reflashes) until erased or
    // overwritten by the next crash.
    size_t cd_addr = 0, cd_size = 0;
    if (esp_core_dump_image_get(&cd_addr, &cd_size) == ESP_OK && cd_size > 0)
      core::logf("crash dump stored (%u bytes) — download at /coredump, "
                 "clear with /coredump?erase=1\n",
                 static_cast<unsigned>(cd_size));
  }
#endif
  platform::crash_record::report_at_boot();  // what the pool looked like when an alloc failed
  g_config.begin();  // create NVS namespace on first boot (quiets read errors)

#if defined(BOARD_DISPLAY_DSI) || defined(BOARD_DISPLAY_RGB)
  // Boot-flag OTA install: an "Install now" tap set a target version and
  // rebooted here. Do the install NOW — before the full app/BLE come up. On the
  // hosted-radio DSI boards this also matters for the DMA pool (a light display
  // is used so the download's SDIO RX can get its contiguous buffer); on native-
  // WiFi RGB boards it's just a clean, self-contained flow. run() shows a
  // progress UI, downloads to PSRAM, writes flash with the screen blanked
  // (flash writes glitch the panel), and reboots. Never returns when set.
  if (!g_config.pending_install().empty()) {
    platform::install_mode::run(g_config);
  }
#endif

#if defined(CONFIG_ESP_HOSTED_ENABLE_BT_NIMBLE)
  // Hosted-radio boards (P4 + C6 over SDIO): the transport must be brought up
  // through Arduino's hosted HAL (esp_hosted_init + connect_to_slave + BT
  // controller RPC) before any NimBLE call. esp-nimble-cpp's init alone lands
  // in the vhci driver with the SDIO link down -> "card init failed" + abort.
  core::logf("hosted radio: bringing up SDIO link to co-processor...\n");
  if (!hostedInitBLE()) {
    core::logf("ERROR: hosted radio init failed; BLE unavailable\n");
  } else {
    core::logf("hosted radio: link up\n");
  }
#endif

  if (!g_display.begin()) {
    core::logf("ERROR: display init failed\n");
    return;
  }
  core::logf("Display up: %d x %d\n", g_display.width(), g_display.height());

  if (g_touch.begin(g_display.width(), g_display.height())) {
    core::logf("Touch up: CST816\n");
  } else {
    core::logf("WARN: CST816 touch not detected on I2C\n");
  }

#if defined(CONFIG_ESP_HOSTED_ENABLE_BT_NIMBLE)
  // One-time co-processor (C6) firmware update: the factory slave is stale
  // (mismatched host lib -> boot RPC timeout + broken RX under load). We flash
  // the embedded matching image now — display is up so we can show progress,
  // and this is the quiet window (WiFi/NimBLE not started yet). Host->slave TX
  // over SDIO, so it works on the stale slave. On success the C6 reboots and we
  // reboot the P4 to re-init the link. See c6_update.cpp.
  // APOLLO_SKIP_C6_UPDATE (build flag, never set by any env): a validation
  // build that leaves the factory C6 slave alone, so a board can be dumped,
  // tried and restored to factory in every respect. The stale slave still
  // works for the basics; only the on-device OTA download needs the update.
#if defined(APOLLO_SKIP_C6_UPDATE)
  core::logf("C6 update: SKIPPED (APOLLO_SKIP_C6_UPDATE build)\n");
  if (false) {
#else
  if (platform::c6_update_needed()) {
#endif
    core::logf("C6 update: needed; applying embedded slave firmware\n");
    lv_obj_t* ov = lv_obj_create(lv_screen_active());
    lv_obj_remove_style_all(ov);
    lv_obj_set_size(ov, lv_pct(100), lv_pct(100));
    lv_obj_set_style_bg_color(ov, lv_color_hex(0x101418), 0);
    lv_obj_set_style_bg_opa(ov, LV_OPA_COVER, 0);
    lv_obj_set_flex_flow(ov, LV_FLEX_FLOW_COLUMN);
    lv_obj_set_flex_align(ov, LV_FLEX_ALIGN_CENTER, LV_FLEX_ALIGN_CENTER,
                          LV_FLEX_ALIGN_CENTER);
    lv_obj_set_style_pad_row(ov, 18, 0);
    lv_obj_t* title = lv_label_create(ov);
    lv_label_set_text(title, "Updating Wi-Fi co-processor");
    lv_obj_set_style_text_color(title, lv_color_hex(0xFFFFFF), 0);
    lv_obj_t* sub = lv_label_create(ov);
    lv_label_set_text(sub, "One-time setup, ~30s - please wait, don't power off.");
    lv_obj_set_style_text_color(sub, lv_color_hex(0xA0A0A0), 0);
    lv_obj_t* bar = lv_bar_create(ov);
    lv_obj_set_size(bar, lv_pct(70), 18);
    lv_bar_set_range(bar, 0, 100);
    lv_obj_t* pctlbl = lv_label_create(ov);
    lv_label_set_text(pctlbl, "0%");
    lv_obj_set_style_text_color(pctlbl, lv_color_hex(0xFFFFFF), 0);
    lv_timer_handler();
    const bool ok = platform::c6_update_apply([&](int pct) {
      lv_bar_set_value(bar, pct, LV_ANIM_OFF);
      char b[8];
      std::snprintf(b, sizeof(b), "%d%%", pct);
      lv_label_set_text(pctlbl, b);
      lv_timer_handler();  // pump the panel between chunks
    });
    core::logf("C6 update: %s\n", ok ? "applied; rebooting" : "failed");
    lv_label_set_text(sub, ok ? "Done - restarting..."
                              : "Update failed - continuing on old firmware.");
    lv_timer_handler();
    Serial.flush();
    delay(1500);
    if (ok) {
      // An OTA-installed image boots PENDING_VERIFY and only confirms itself
      // after 60 s of loop() (below). This restart would land inside that
      // window and the bootloader would read it as a bootloop and roll the
      // update back — on a board whose C6 was still factory, EVERY OTA would
      // fail that way (X-8, beta.2, 2026-09-22). The image has brought up the
      // display and the hosted link to get here, which is the proof the
      // 60 s health check stands for, so confirm it now.
      const esp_partition_t* run = esp_ota_get_running_partition();
      esp_ota_img_states_t st;
      if (esp_ota_get_state_partition(run, &st) == ESP_OK &&
          st == ESP_OTA_IMG_PENDING_VERIFY) {
        esp_ota_mark_app_valid_cancel_rollback();
        core::logf("OTA: new image confirmed before the C6 restart\n");
      }
      esp_restart();  // reboot P4 so the hosted link re-inits on new slave
    }
    lv_obj_delete(ov);      // failure: drop the overlay and boot normally
  }
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
void loop() {
  poll_serial_id();          // web-flasher "which board is this?" responder
  g_brew.poll(millis());     // paddle relay + shot state machine (edge-critical)
  // Frame-cost telemetry, replacing LVGL's on-screen perf overlay (which is a
  // DEBUG tool that had been shipping enabled -- see lv_conf.h -- and which
  // redraws every frame, inflating the very numbers it reports). This costs
  // two micros() pairs per iteration and reports over serial instead of on
  // the glass. The graph pump is timed separately: a shot plot's full-canvas
  // repaints (window growth, Y rescale) land there, not in lv_timer_handler.
  {
    const uint32_t tp0 = micros();
    g_app.pump_scale_chart();  // drain the scale's flow stream into the graph
    const uint32_t pump_dt = micros() - tp0;
    const uint32_t t0 = micros();
    lv_timer_handler();      // LVGL render/input
    const uint32_t dt = micros() - t0;
    static uint32_t acc = 0, iters = 0, worst = 0, last = 0;
    static uint32_t pacc = 0, pworst = 0;
    acc += dt;
    pacc += pump_dt;
    ++iters;
    if (dt > worst) worst = dt;
    if (pump_dt > pworst) pworst = pump_dt;
    if (millis() - last >= 60000) {  // telltale cadence, matches the heap line
      last = millis();
      core::logf("lvgl: %u frames, avg %u us, worst %u us (%u%% of wall)\n",
                 static_cast<unsigned>(iters),
                 static_cast<unsigned>(iters ? acc / iters : 0),
                 static_cast<unsigned>(worst),
                 static_cast<unsigned>(acc / 600000));  // % of the 60s window
      core::logf("pump: avg %u us, worst %u us (%u%% of wall)\n",
                 static_cast<unsigned>(iters ? pacc / iters : 0),
                 static_cast<unsigned>(pworst),
                 static_cast<unsigned>(pacc / 600000));
      acc = iters = worst = 0;
      pacc = pworst = 0;
    }
  }
  g_token_setup.handle();    // portal auto-close timeout
  platform::crash_record::watch();  // DMA-pool low-water tripwire (logs a census)
  g_web_ui.poll();           // S3 boards serve here; no-op on the P4s (task)

#if defined(BOARD_DISPLAY_RGB)
  // One-shot raster resync at 2 s for the boot ghost (~1/4 of cold boots come
  // up latched a few px off from underruns while setup floods the PSRAM bus).
  // The resync is VSYNC-aligned (armed here, executed inside vertical
  // blanking by the display's resync task) but still shows a one-frame ~5 px
  // jump — the bounce-buffer refill runs with the timing engine stopped —
  // which is why it's NOT on a periodic timer: the user found a 5 s cadence
  // distracting. Runtime ghosts are healed manually via Settings > "Restart
  // display" instead. (An earlier mid-frame, non-VSYNC-aligned version was
  // far worse: full blank AND could itself latch a fresh ghost — keep the
  // alignment if refactoring.)
  static bool boot_resync_done = false;
  if (!boot_resync_done && millis() >= 2000) {
    boot_resync_done = true;
    g_display.rgb_resync(/*verbose=*/false);
  }
  g_display.rgb_poll();  // resync outcome + bounce parity fix log (display.cpp)
#endif

  // Internal-heap telltale, once a minute: the S3 boards live close to the
  // internal-RAM ceiling (on-chip WiFi+BLE + task stacks + DMA buffers), and
  // every starvation bug so far surfaced as some SILENT downstream failure.
  // With this line in the log, the next one arrives with numbers attached.
  //
  // Sampled every 250ms and reported as a MINIMUM, because a once-a-minute
  // reading misses every transient: an update fetch lasts ~1s, a BLE scan a few
  // seconds, and those dips are exactly what starve the WiFi driver's RX pool.
  //
  // Both capability masks are reported. Plain INTERNAL also counts 32-bit-only
  // IRAM, which ordinary allocations (malloc, task stacks, lwIP pbufs, WiFi RX
  // buffers) can NEVER use — measured 2026-09-09 on the 4.3C, plain INTERNAL
  // read 13812 while 8BIT read 8180 at the same moment. 8BIT is the number that
  // decides whether an allocation actually succeeds; anything gating on plain
  // INTERNAL reads ~5.6KB high. The gap is logged so it stays visible.
  // COST NOTE: heap_caps_get_largest_free_block() WALKS THE HEAP holding the heap
  // lock, so it is not free to call often — it blocks other tasks' allocations
  // and janks the UI. Measured 2026-09-09 that plain INTERNAL and INTERNAL|8BIT
  // return identical values on this board, so only the 8BIT walk is kept, at
  // 500ms — still 2-4 samples across a ~1-2s fetch, at a quarter the cost of the
  // first cut (two walks every 250ms).
  // DMA-CAPABLE is tracked separately and it is the one that matters: the
  // hardware AES engine (and the LCD/SDIO DMA paths) allocate from
  // MALLOC_CAP_INTERNAL|MALLOC_CAP_DMA, which is a NARROWER pool than 8BIT.
  // Measured 2026-09-10 on the 4.3C: 8BIT reported a comfortable ~7KB largest
  // while esp-aes could not allocate at all mid-TLS, failing every update
  // check. Everything we logged until now was blind to that. See the
  // p4-dma-capable-heap notes -- the same trap, on the other chip.
  // NOTE: the old 500ms sampler that used to live here was structurally blind.
  // It ran in loop(), so it could never observe a dip that happened INSIDE one
  // loop iteration -- e.g. while handleClient() served a request, which is
  // exactly the event we suspect. heap_caps_get_minimum_free_size() is the
  // allocator's OWN low-water mark, updated on every alloc/free, so it has no
  // sampling blind spot and costs nothing to read. It tracks free bytes rather
  // than largest block (the allocator doesn't track that), which is the one
  // thing the sampler did give us -- so largest is still read at log time.
  static uint32_t last_heap_log_ms = 0;
  if (millis() - last_heap_log_ms >= 60u * 1000u) {
    last_heap_log_ms = millis();
    // loop_hw = bytes of THIS task's stack never touched. ARDUINO_LOOP_STACK_SIZE
    // is 16KB by guess (a past overflow on theme rebuild + WiFi bring-up); this
    // is the number to size it from.
    core::logf(
        "heap: 8bit free=%u largest=%u lowest=%u | DMA free=%u largest=%u lowest=%u | "
        "loop_hw=%u\n",
        static_cast<unsigned>(
            heap_caps_get_free_size(MALLOC_CAP_INTERNAL | MALLOC_CAP_8BIT)),
        static_cast<unsigned>(heap_caps_get_largest_free_block(
            MALLOC_CAP_INTERNAL | MALLOC_CAP_8BIT)),
        static_cast<unsigned>(heap_caps_get_minimum_free_size(
            MALLOC_CAP_INTERNAL | MALLOC_CAP_8BIT)),
        static_cast<unsigned>(
            heap_caps_get_free_size(MALLOC_CAP_INTERNAL | MALLOC_CAP_DMA)),
        static_cast<unsigned>(heap_caps_get_largest_free_block(
            MALLOC_CAP_INTERNAL | MALLOC_CAP_DMA)),
        static_cast<unsigned>(heap_caps_get_minimum_free_size(
            MALLOC_CAP_INTERNAL | MALLOC_CAP_DMA)),
        static_cast<unsigned>(uxTaskGetStackHighWaterMark(nullptr)));
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

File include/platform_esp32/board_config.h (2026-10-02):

#pragma once

#include <cstdint>

// Per-board pin & panel configuration. Exactly ONE board is selected at build
// time via a -DBOARD_* flag in platformio.ini. This is the single place board
// pins live — driver code reads these constants and never hardcodes a pin.
//
// To add a board (e.g. the 4.3 RGB panel later), add another #elif block with
// the same constant names that that board's driver needs.
//
// kUpdateSlug is `inline` on purpose and must STAY inline: a plain
// `constexpr char[]` has internal linkage, so every translation unit that uses
// it gets its OWN copy of the string, and the release workflow asserts the
// slug appears EXACTLY ONCE in the binary (it is the self-updater's URL — two
// copies fail the build, as adding a second user of it did).

namespace board {

#if defined(BOARD_WAVESHARE_S3_LCD_2)

// Waveshare ESP32-S3-Touch-LCD-2 — 2.0", 240x320 ST7789T3 over 4-wire SPI,
// CST816 capacitive touch over I2C. Values traced to Waveshare's demo source.
constexpr char kName[] = "Waveshare ESP32-S3-Touch-LCD-2";
// INTERNAL-ONLY board: deliberately NOT in the firmware-release.yml
// matrix, the web flasher, or the docs, so nothing is published at
// firmware/app/<slug>.bin and self-update cannot complete here (the
// check still runs and the download 404s — accepted, see CLAUDE.md
// "Support matrix"). The slug is kept so promoting the board later is
// just a matrix row.
inline constexpr char kUpdateSlug[] = "s3-touch-lcd-2";
#define BOARD_DISPLAY_SPI    // ST7789 over SPI
#define BOARD_TOUCH_CST816   // CST816, 8-bit registers
constexpr bool kSupportsBrightness = true;  // LEDC PWM backlight (dimmable)
// Screensaver Dim floor (SaverMode::kDim). LEDC is linear here; keep the S3 boards consistent.
constexpr int kSaverDimPercent = 10;

// --- Display: ST7789 on the FSPI bus ---
constexpr int  kLcdSclk = 39;
constexpr int  kLcdMosi = 38;
constexpr int  kLcdMiso = 40;
constexpr int  kLcdCs = 45;
constexpr int  kLcdDc = 42;
constexpr int  kLcdRst = -1;          // no reset line; tied to system reset
constexpr int  kLcdBacklight = 1;     // active-high; PWM-capable (LEDC) later
constexpr int  kLcdNativeW = 240;     // panel native size (portrait)
constexpr int  kLcdNativeH = 320;
constexpr int  kLcdRotation = 1;      // 1 => 320x240 landscape (vendor default)
constexpr bool kLcdIps = true;
constexpr long kLcdSpiHz = 80000000;  // 80 MHz

// --- Touch: CST816 on I2C ---
constexpr int  kTouchSda = 48;
constexpr int  kTouchScl = 47;
constexpr int  kTouchAddr = 0x15;
constexpr int  kTouchRst = -1;        // no reset line
constexpr int  kTouchInt = -1;        // not wired in vendor demo; we poll
// Touch reports coordinates in the panel's native (portrait) orientation; the
// display runs rotated. These map native -> on-screen. Best-guess for
// rotation=1; flip a flag if a tap lands in the wrong place (see serial log).
constexpr bool kTouchSwapXY = true;
constexpr bool kTouchMirrorX = false;
constexpr bool kTouchMirrorY = true;

// --- Battery monitoring (from the vendor demo) ---
// GPIO5 = ADC1_CH4, battery divided by 3. Use analogReadMilliVolts for the
// calibrated reading. NOTE: GPIO5 is also a MOSFET-control solder pad on this
// board — we only ever read it as an ADC input. No charge-status pin: the node
// voltage alone decides USB vs battery (kUsbPowerVolts, see core/battery.h).
constexpr int   kBatteryAdc = 5;             // ADC GPIO reading battery voltage
constexpr float kBatteryDivider = 3.0f;      // battery_volts = adc_volts * divider
// Full reads ~4.13 V at rest on this board's ADC path (measured: 92% with the old
// 4.20 cap, charge-current = 0), so cap there to read ~100% when full.
constexpr float kBatteryFullVolts = 4.13f;
constexpr float kBatteryEmptyVolts = 3.40f;  // 0% with margin above the brownout zone
constexpr float kBatteryCutoffVolts = 3.40f; // deep-sleep at/below this (avoids brownout)
constexpr float kBatteryResumeVolts = 3.70f; // only wake fully once charged past here
constexpr float kUsbPowerVolts = 4.15f;      // node at/above this => external (USB) power

// --- Paddle control (brew-by-weight) ---
// Drive line into the Micra's paddle circuit (a relay, or the 4.3B's opto-
// isolated GPIO). The Micra just watches this line: we hold it to keep a shot
// running and release it to stop. kPaddleSensePin reads the physical paddle.
// -1 = no paddle hardware wired on this board -> auto-stop disabled, the scale
// is display/timer/flow/alert-only. (This 2-inch is a portable battery remote;
// wire a relay to spare GPIOs and set these if you want auto-stop here.)
constexpr int  kPaddleDrivePin = -1;
constexpr int  kPaddleSensePin = -1;
constexpr bool kPaddleActiveHigh = true;   // drive level that "closes" the shot
constexpr int  kLinkDrivePin = -1;  // no Apollo Link pin set on this board
constexpr int  kLinkSensePin = -1;
constexpr int  kLinkCtrlPin  = -1;

#elif defined(BOARD_WAVESHARE_S3_LCD_7B)
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

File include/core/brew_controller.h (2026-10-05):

#pragma once

#include <cstdint>
#include <functional>

#include "core/brew.h"
#include "core/paddle.h"
#include "core/scale.h"
#include "core/shot_detector.h"
#include "core/shot_timer.h"

namespace core {

// The brew-by-weight state machine (see brew.h for the lifecycle). Pure logic
// over the IPaddle + IScale ports; the caller pumps poll(now_ms) from its main
// loop (a few ms cadence — paddle sensing is internally throttled) and wires
// the persister callbacks to whatever config store the platform has.
//
// Single-threaded by design: poll() and every setter/snapshot() must run on the
// same task (the device loop / UI task). IScale::snapshot() is internally
// thread-safe against its BLE task; IScale::tare() only sets a flag.
class BrewController : public IBrewController {
 public:
  BrewController(IPaddle& paddle, IScale& scale)
      : paddle_(paddle), scale_(scale) {}

  // Wire before the loop starts (all optional).
  // Returns true when the machine is KNOWN to be connected and not brewing-
  // capable (standby/off). The Micra treats a paddle flip in that state as its
  // wake switch — it powers on, no water moves — so the controller passes the
  // level through to the machine but skips the shot timer + automation.
  void set_standby_provider(std::function<bool()> p) { standby_ = std::move(p); }
  // A scale is PAIRED (saved on this unit), connected or not. Without one the
  // effective mode is kManual: Shot detect could never see a shot and Auto
  // could never stop one, and the pass-through relay must not refuse a flip
  // "because the scale is missing" when there is no scale to miss. The stored
  // mode is untouched and returns the moment a scale is paired. Unset = known.
  void set_scale_known_provider(std::function<bool()> p) { scale_known_ = std::move(p); }
  void set_target_persister(std::function<void(float)> p) { persist_target_ = std::move(p); }
  void set_shot_mode_persister(std::function<void(int)> p) { persist_mode_ = std::move(p); }
  void set_overshoot_persister(std::function<void(float)> p) { persist_overshoot_ = std::move(p); }
  void set_hint_overshoot_persister(std::function<void(float)> p) { persist_hint_overshoot_ = std::move(p); }
  void set_review_hold_persister(std::function<void(int)> p) { persist_review_ = std::move(p); }
  void set_detect_lead_in_persister(std::function<void(int)> p) { persist_lead_in_ = std::move(p); }
  void set_wired_paddle_persister(std::function<void(bool)> p) { persist_wired_ = std::move(p); }
  void set_flush_persister(std::function<void(int)> p) { persist_flush_ = std::move(p); }
  void set_flush_delay_persister(std::function<void(int)> p) { persist_flush_delay_ = std::move(p); }

  // Seed from persisted config at boot (does not re-persist). `mode` is the
  // persisted ShotMode as an int (clamped here so a stale NVS value is safe).
  void seed(float target_g, int mode, float overshoot_g, int review_hold_s,
            bool wired_paddle, int flush_s, int flush_delay_s,
            float hint_overshoot_g, int detect_lead_in_s) {
    target_g_ = target_g;
    mode_ = (mode < 0 || mode > 2) ? ShotMode::kDetect : static_cast<ShotMode>(mode);
    overshoot_g_ = overshoot_g;
    overshoot_saved_ = overshoot_g;
    hint_overshoot_g_ = hint_overshoot_g;
    hint_overshoot_saved_ = hint_overshoot_g;
    review_hold_s_ = review_hold_s;
    wired_paddle_ = wired_paddle;
    flush_s_ = flush_s;
    flush_delay_s_ = (flush_delay_s < 1) ? 3 : flush_delay_s;
    detect_lead_in_s_ =
        (detect_lead_in_s < 0 || detect_lead_in_s > 10) ? 3 : detect_lead_in_s;
  }

  void poll(uint32_t now_ms);

  BrewSnapshot snapshot() const override;
  void set_target_weight_g(float grams) override;
  void set_shot_mode(ShotMode mode) override;
  void dismiss_review() override;
  void set_review_hold_s(int seconds) override;
  void set_detect_lead_in_s(int seconds) override;
  void set_wired_paddle(bool on) override;
  void set_flush_s(int seconds) override;
  void set_flush_delay_s(int seconds) override;
  void toggle_manual_flush() override;
  bool start_backflush() override;
  void cancel_backflush() override;
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

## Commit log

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2026-06-28 Live machine data on Home + working power button
    - core::IMachine gains set_power(); the UI holds a core::IMachine& and both
    renders state and issues commands through it, never seeing the transport.
    - Home tab split into build + in-place update (update_home); ui::App retains
    widget handles and refreshes from snapshots instead of rebuilding.
    - Power button wired to IMachine::set_power. MicraLink::set_power sends the BLE
    command then re-reads its cached snapshot so the UI reflects it promptly.
    - Device polls the machine every 3s and pushes values into the UI; the debug
    serial logging is removed.
    - FakeMachine gains set_power for parity (and future sim interactivity).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
    [main.cpp]
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2026-06-28 Battery icon stays put; add 800x480 Settings render
    - Fixed-width, left-aligned battery label so the battery glyph never moves; the
    charge bolt now renders to the RIGHT of the icon (in the percent's slot)
    instead of in front of it.
    - Sim also renders renders/settings_800x480.png (wide Settings), like Home.
    [main.cpp]
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2026-06-28 Brew & boiler temperature controls
    - IMachine gains set_brew_target / set_steam_target; MicraLink posts them to its
    task as SettingBoilerTarget commands (CoffeeBoiler1 = %.1f, SteamBoiler = int)
    then refreshes. FakeMachine implements them so the sim reflects edits.
    - Settings Brew/Boiler panels are steppers:
    - Brew: [-] value [+], short-press +/-0.1 C, long-press (+repeat) +/-0.5 C
    snapped to the 0.5 grid, clamped to kBrewTargetMin/MaxC.
    - Boiler: 3 steam levels (126/128/131 C) showing actual value + "Level N of 3".
    - Stepping only changes the LOCAL value; the BLE write is deferred to
    commit_temp_edits() on exit (section switch or main-tab change) so we don't
    write on every p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
    [main.cpp]
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2026-06-29 Auto-read token in pairing mode, fall back to WiFi with a choice modal
    - On "learn machine", MicraLink first tries to read the auth token from the
    pairing-mode characteristic (0c). If it returns a real token, it's adopted +
    persisted (via a token-persister callback) and the link connects — no WiFi.
    Otherwise the link settles in NeedsToken.
    - IProvisioner.retry_pairing() re-attempts the read; save_device kicks off the
    first attempt.
    - UI: tapping a scanned device shows "Pairing...", then on success jumps to Home,
    or on failure pops a token-setup modal: [Retry pairing] / [WiFi] / [Cancel].
    The Settings "Setup" button opens the same modal. Generalized the modal helper
    (open_moda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
    [main.cpp]
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2026-06-29 Add a wall clock: top-bar time + "Set time" in Device settings
    - New core::IClock port; platform_esp32::Clock drives the ESP32 internal RTC
    (LiPo-backed; a PCF85063 board would slot in behind the same port). host
    FakeClock for the sim.
    - Home top bar shows "H:MM" at the far right (macOS-style), with the battery to
    its left; "--:--" until the clock is set.
    - Device section gains Hour/Minute steppers (tap = +/-1, hold to spin; wraps);
    editing sets the clock live. Re-seeded from the clock on entering the section.
    - Shortened the Home status "Token needed - Settings" -> "Token needed" to make
    room for the clock.
    [main.cpp]
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2026-06-29 Swappable color schemes (5 themes) selectable in Device settings
    - Abstract all UI colors into ui::theme: a Palette struct of roles (bg/rail/card,
    text/muted, accent, scrollbar, ok/warn/alert) + runtime accessors that read the
    active palette. Five dark schemes: Midnight, Graphite, Espresso, Nord,
    Solarized. All 60 call sites now use the accessors instead of constants.
    - Persist the choice via core::IDisplaySettings::theme()/set_theme() (NVS "theme"
    key); host fake mirrors it.
    - Device settings gets a "Theme" button: tap cycles schemes. Applying re-reads
    the palette and rebuilds the UI (deferred via lv_async_call so the click's own
    widget can be torn down safely); the rebuild rest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
    [main.cpp]
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2026-06-29 Add an XL layout tier for 1024x600 (7" panel)
    ui::is_xl(screen) (width >= 960) selects a scaled-up variant of the wide layout:
    larger padding, row heights, control sizes, and secondary fonts, on the same
    side-rail structure. Sim now renders home/settings/boiler/device at 1024x600.
    Note: kept tab icons and stepper +/- glyphs at montserrat_28 even on XL — a 48px
    glyph inside those small buttons triggers an LVGL software-label draw loop (same
    class of bug seen before). The big temp value stays 48 (free label, fine).
    [main.cpp]
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2026-06-29 Add ESP32-S3-Touch-LCD-7B board support (1024x600 RGB)
    Best-shot firmware for the 7" board, traced from Waveshare's own 7B Arduino demo
    (examples 06_LCD / 08_TOUCH) — compiles, not yet hardware-verified.
    - board_config.h: 7B block with feature macros (BOARD_DISPLAY_RGB / TOUCH_GT911
    / HAS_IO_EXTENSION) + RGB pins, panel timing (30 MHz, the demo porches), GT911
    on I2C 8/9 (INT GPIO4), and the IO-extension pin map. 2-inch block tagged
    BOARD_DISPLAY_SPI / TOUCH_CST816.
    - display.cpp: board-conditional. RGB path brings up the IO extension, releases
    LCD reset, drives backlight, and creates an Arduino_RGB_Display; SPI path
    unchanged. Backlight is the IO-extension PWM/enable on RGB, LE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
    [board_config.h]
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2026-06-29 7B: add RGB bounce buffer (fix flicker/tearing); quiet first-boot NVS logs
    The 7B's RGB framebuffer is in PSRAM; at 30 MHz the LCD peripheral underruns
    streaming it, causing flicker/tearing. Add a bounce buffer (internal RAM, refilled
    from PSRAM) sized H_RES*10 per Waveshare's demo — the standard fix. Also: move the
    LVGL draw buffer to PSRAM (RGB needs no DMA), drop the red diagnostic fill now the
    panel's confirmed, and create the NVS namespace on boot so a fresh device stops
    logging "nvs_open failed: NOT_FOUND" on every config read.
    [board_config.h, main.cpp]
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2026-06-29 7B: calibrate battery ADC scale (4.026V @ raw 418) + oversample
    Measured 4.026 V at the terminals with raw ~418, so volts/count = 4.026/418 =
    0.009632 (the vendor ESP32-ADC formula doesn't apply to this chip's ADC). Also
    oversample the read 16x — the earlier jitter was a floating input with no battery
    connected; with a pack attached it's steady to ~+/-2 counts.
    [board_config.h]
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2026-06-29 Stats tab: enable it and build out the graph + info views
    The "build hang" that parked this was the LVGL pool exhaustion (now fixed), so the
    tab is wired up. The graph (Brew/Boiler):
    - Y-axis temperature labels + a bottom time scale (drawn in a chart overlay; this
    LVGL chart widget has no native axes), with a tight range so the curve fills it.
    - A set-point reference line at the current target.
    - No-data spans greyed — both a leading "before recording" span and mid-stream
    gaps (e.g. BLE dropped while the device kept running); "No data yet" when empty.
    - Tap the chart to cycle the time window (drops the redundant title/value/zoom
    button — the selector names the section and the Y axi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
    [main.cpp]
2026-06-29 7B: revert RGB PCLK back to 30 MHz
    24 MHz dropped below the panel's stable pixel-clock range (no image). 30 MHz is
    the Waveshare demo value and works; residual tearing is the single-framebuffer
    limitation, not PCLK, so chasing it here doesn't help.
    [board_config.h]
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2026-06-29 History: sample every 2 min and interpolate short gaps
    Drop the sample cadence from 30 s to 2 min (~720 samples for 24 h, ~8.6 KB vs
    ~34 KB) — plenty of resolution for the chart, lighter on RAM. Since LVGL's chart
    is index-based and breaks the line at any empty point, series() now fills short
    empty-bucket runs by linear interpolation (over the fixed 96 chart buckets, so
    it's cheap) — keeping the line continuous on short windows while leaving long
    empty spans (machine off / BLE dropped) as real gaps.
    [main.cpp]
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2026-06-30 Battery: calibrate full per board; 0% at 3.4 V
    Measured "full" (charge current = 0) read 86% on the 7B and 92% on the 2-inch with
    the old 4.20 V cap, so the packs rest ~4.07 V (7B IO-ext ADC) / ~4.13 V (2-inch
    ADC) when full — set kBatteryFullVolts there so full reads ~100%. Raise empty to
    3.4 V on both so 0% sits with margin above the brownout zone.
    [board_config.h]
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2026-06-30 Battery: deep-sleep at the low-voltage cutoff to avoid brownout thrash
    Near empty the rail sags under load and the percent thrashes (then the device
    browns out). Instead, expose the smoothed pack voltage in BatteryState and, when it
    holds at/below kBatteryCutoffVolts (3.4 V, both boards) on battery for ~3 s, hand
    off to a device deep-sleep: kill the backlight (dominant load, can latch on in
    sleep) and esp_deep_sleep with a 30 s timer wake, so plugging in recovers it (the
    voltage rises above cutoff and it stops re-sleeping). The cutoff check + handler
    live in the App (portable); the device supplies the sleep action and the per-board
    threshold.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
    [board_config.h, main.cpp]
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2026-06-30 Battery: deep-sleep parks until touch + charge, never half-boots
    Replace the timer-poll re-check (which full-booted every 30 s -> the screen
    flashing on intermittently) with a true power-down that wakes on a screen touch.
    At the cutoff: backlight off, then esp_deep_sleep with ext0 wake on the touch
    controller's INT line where it's an RTC GPIO (7B GPIO4; the 2-inch has no INT
    wired, so it wakes on reset). Draw is ~uA, not "running with the backlight off."
    On any wake from the park (touch or reset), a dark check reads the pack WITHOUT
    powering up the panel/LVGL/BLE and refuses to fully boot unless it's charged past
    kBatteryResumeVolts (3.7 V, hysteresis above the 3.4 V cutoff so the at-rest
    v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
    [board_config.h, main.cpp]
2026-06-30 Scale integration (Phases 0-3): BLE Bookoo scale + scale-aware UI
    Checkpoint. Bluetooth coffee-scale support and the apollo/goscale-inspired
    UI reshaping, all driven through new core ports so it runs in the sim and
    on-device unchanged. Brew-by-weight (paddle GPIO) is scaffolded but not yet
    wired (Phase 4).
    Core ports: IScale, IScaleProvisioner, IBrewController (+ host fakes).
    Settings: rebuilt as an lv_menu drill-in grouped by device --
    Micra/Scale/Device, each with nested Bluetooth | Settings pages; styled
    back-button chip + centered titles.
    Home: scale-aware layout chosen at build time. Compact = weight hero +
    tare/paddle; large = a short brew/boiler/scale readout row above a
    flow-rate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
    [board_config.h, brew_controller.h, main.cpp]
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2026-07-01 Add Waveshare ESP32-S3-Touch-LCD-4.3B board (800x480 RGB)
    The 4.3B is the target device. It's the 7B RGB path shrunk to 800x480 —
    same RGB pin mapping / GT911 touch / I2C bus — so it reuses those backends;
    only board_config's resolution + panel timing (16 MHz pclk, 4.3B porches)
    differ. New env esp32-s3-micra-4-3b + make/flash-4-3b targets + flash.sh
    board detection ("LCD-4" banner).
    Chip differences from the 7B, handled per-board:
    - IO expander is a real CH422G, not the 7B's register-based part. It's driven
    by single-byte writes to distinct command addresses (0x24 config / 0x38 IO /
    0x23 OC); the 7B's reg+value writes NACK and poison the I2C bus (which broke
    touch). io_extension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
    [board_config.h, main.cpp]
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2026-07-01 Flow graph: derive g/s from weight, scope mode, taller Settings buttons
    Settings:
    - Bump nav rows, connect/forget/scan, and the Back button up to Home's
    btn_h so they aren't cramped on wide/xl; center the Back contents.
    Flow graph:
    - Blank the plot when the scale disconnects instead of scrolling a
    fake zero line.
    - Keep both weight (g) and flow-rate (g/s) per column so the g/s<->g
    toggle re-scales and redraws the existing trace instead of clearing.
    - Derive flow ourselves as the signed rate of weight gain over a short
    window (scales only reliably stream weight); drop the unused packet
    "flow" field and its drain_flow/pending_flow plumbing. A "Drop
    negative g/s" setting floors out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
    [main.cpp]
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2026-07-02 WiFi station + NTP time sync; Home polish; scale-forget crash fix
    Add optional WiFi station mode: the device can join the customer's home
    WiFi and keep its clock correct via NTP (with a POSIX-TZ timezone for
    automatic DST). Off by default.
    - New core::INetwork port + platform_esp32::Network (STA + SNTP) and a
    host FakeNetwork stub for the sim, injected like the other ports.
    - Credentials are entered over the SAME AP web portal as the Micra token
    (token_setup extended with SSID/password + /wifi); fire-and-forget, the
    device screen (NetState) is the source of truth, so no concurrent AP/STA.
    Failed creds auto-reopen the AP; Settings "Set up WiFi" always raises it.
    - NTP: syncs on conne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
    [main.cpp]
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2026-07-02 Docs: use 800x480 screenshots as the reference size
    Add device + stats brew renders at 800x480 to the sim and swap the README's
    settings/stats screenshots to them, so all docs/img shots share the 800x480
    (4.3B) reference form factor. Other sizes are reserved for demonstrating the
    responsive/multi-size layouts.
    [main.cpp]
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2026-07-18 p4: hardware bring-up — boots, display, touch, and hosted BLE all working
    First run on real hardware (chip is rev v1.3 engineering-sample silicon)
    surfaced three faults, all fixed:
    - Boot: images built for the default rev>=3.0 target crash in the 2nd-stage
    bootloader (illegal instruction at its entry). Fix: chip_variant
    "esp32p4_es" in the board json selects the core's prebuilt rev v1.x libs
    and matching linker templates (same fix as arduino-esp32 PR #12341).
    Platform pinned to 55.03.39 explicitly — the "stable" URL label doesn't
    force a reinstall and can silently mix builder/framework versions.
    - BLE: esp-nimble-cpp's init drops into the hosted vhci path with the SDIO
    link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
    [main.cpp]
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2026-07-18 p4/ui: 2px flow trace; nudge P4 panel refresh to ~66Hz
    - Flow line thickness is now a named constant (kHalfWidth); 1.25 reads as
    ~2px with the AA feather. Chosen on hardware over the ~1.5px default.
    - DPI clock 30MHz -> 33.4MHz (~60Hz -> ~66Hz) to move the panel's faint
    VCOM/inversion shimmer off 60Hz. Inconclusive-but-harmless on the test
    board; comment documents how to revert.
    [board_config.h]
2026-07-18 p4: battery level via BAT_ADC (GPIO20, ÷3 divider); log reset reason at boot
    - Enable the direct-ADC battery path on the P4 4.3: GPIO20 through a ÷3
    divider, confirmed empirically (raw*3 == 4.20V, the LiPo CV charge level,
    while on USB). Fixes the permanent plug icon (kBatteryAdc=-1 forced the
    no-battery fallback). Bring-up calibration log stays in battery.cpp
    (throttled, P4-only) until the divider survives a few discharge cycles.
    - HWCDC::isPlugged() is non-functional on the P4's USB-Serial-JTAG (always
    false), so charging detection relies on the voltage threshold fallback.
    - Boot banner now prints esp_reset_reason (all boards). Used it to confirm
    the USB plug/unplug reboot wi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
    [board_config.h, main.cpp]
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2026-07-18 4.3c: board support — 4.3B panel + 7B-style IO extension (PWM backlight, battery ADC)
    Config-only: the 4.3C is the 4.3B's RGB/GT911/RTC wiring with the register-
    based expander (CH32V003 @0x24) instead of a CH422G, so the existing 7B
    driver paths cover dimming (PWM reg, inverted duty) and battery (ADC reg,
    scale 3*3.3/1023 — not yet multimeter-calibrated). RGB timings from the 4.3C
    demo. Verified on hardware: display, touch, dimming, battery/USB icon.
    [board_config.h]
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2026-07-18 ui: flow graph — oscilloscope mode default, 45s window, 10g weight-mode floor
    Scope sweep becomes the default style (saved NVS choices are untouched; the
    sim's dedicated render flips to showing the scroll variant instead). Window
    shortened 60s -> 45s; weight ('g') mode's default Y full-scale drops
    30g -> 10g so a shot fills the plot sooner. home-scale.png refreshed.
    [main.cpp]
2026-07-18 brew-by-weight: paddle relay + shot automation on the 4.3C (verified on HW)
    Core (platform-free, over new IPaddle + existing IScale ports):
    - core::BrewController state machine: Idle -> Brewing -> Settling -> Review.
    Paddle relayed edge-triggered unconditionally (ESP stop leaves the line open
    until the user's next edge; reboot with paddle-on never auto-starts).
    - Shot start (armed + scale): tare only if the scale isn't already ~0
    (pre-tared = no hold, no dropped samples); baseline confirms event-driven
    the moment the tare lands (~100-300ms), 1.2s deadline as fallback only.
    - Auto-stop at target - overshoot; overshoot LEARNED apollo-style from each
    auto-stopped shot's settled weight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
    [board_config.h, brew_controller.h]
2026-07-18 shot graph: dynamic X axis, event-locked sampling, perf; Micra auto-connect
    Shot plot (verified on HW): during a shot the graph maps time->X — the window
    opens at 10s (max resolution for a young shot) and grows in 5s snaps to the
    45s cap, sliding past it. Between snaps only new right-edge columns paint
    (tiny invalidates, sweep-cheap); full repaints only on snap/rescale/toggle.
    Settling records the drip tail (now 3s); review freezes the plot; Reset (or
    timeout) returns to the live sweep.
    Scale-agnostic data path: ScaleSnapshot.seq ticks per BLE notify. The shot
    plot samples event-locked at the scale's own stream rate (100ms floor so a
    20Hz scale can't outrun the 45s ring), and the flow der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
    [brew_controller.h, main.cpp]
2026-07-18 shot graph: smooth edge animation + tunable curve smoothing
    Edge animation: the trace's leading edge glides toward the last-received
    sample (interpolated through recorded points) instead of jumping a whole
    event-span per notify — display runs ~2 event intervals behind wall clock
    (imperceptible; self-scales to the stream rate). The painted frontier never
    passes recorded data (a stream stall pauses the edge — painting bare columns
    left permanent gaps) and stops strictly before the SECOND-newest sample so
    every painted column's smoothing kernel is complete (capping at the newest
    painted one-sided values under BLE jitter -> permanent kinks at higher
    smoothing levels). A final full paint on r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
    [brew_controller.h]
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2026-07-18 home: device-card redesign + sleep-aware scale UI
    Phases 4-5 of the multi-scale plan (phase 3, the multi-scale registry,
    dropped — scan-and-learn switching is enough).
    - ScaleFeatures grows a `sleep` flag: a sleep-capable scale (Umbra)
    keeps advertising while dozing and wakes on connect. The Acaia driver
    reports it from the detected generation, or from an UMBRA name hint
    before the first connect.
    - Large scale-aware Home: the MICRA/SCALE cards fill the upper half and
    the flow graph the lower half; the bottom action bar is gone. Power/
    Standby moved into the MICRA card below the temp steppers;
    Connect/Disconnect + Tare sit side by side in the SCALE card (for the
    Umbra the con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
    [main.cpp]
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2026-07-18 brew: swallow paddle flips during shot review + scale battery icon
    Paddle relay exception (the only one): an ON edge during kReview no
    longer runs the machine. Automation only re-arms from kIdle, so relaying
    there silently ran a MANUAL shot when the user expected an auto one.
    The edge now ticks BrewSnapshot.review_reject_seq and the UI pulses the
    Reset button in warn ("deal with this first"); the matching OFF edge is
    a harmless no-op. Everything outside review is unchanged.
    SCALE card header also gains an icon-only battery estimate right of the
    status text (shown when the connected scale reports a level; alert color
    under 15%).
    [brew_controller.h]
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2026-07-18 sound: button-press click on audio boards (4.3C ES8311) + acaia frame diag
    New core::ISound port; the 4.3C implements it with a minimal ES8311
    driver (DAC path only, register sequence distilled from the vendor
    demo's esp_codec_dev es8311.c): I2S1 master @ 44.1kHz/16-bit with MCLK
    on GPIO6, data out GPIO15 (the vendor demo header corrects the wiki's
    pin table), codec control on the shared I2C bus, PA enable EXIO4. The
    click is a pre-rendered ~14ms decaying 1.9kHz tick written into the
    I2S DMA on demand (auto_clear keeps underruns silent). Other boards
    compile a stub (available() = false).
    Every ui::make_button() button fires a press hook on LV_EVENT_PRESSED
    — the moment a button activates,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
    [board_config.h, main.cpp]
2026-07-18 sound: on-demand I2S (fixes BLE breakage) + tab-button clicks
    The always-running I2S engine (MCLK/BCLK clocking silence from boot,
    standing DMA + per-descriptor interrupts) broke BLE outright — Micra
    and scale both stuck in Connecting. The channel is now enabled only
    while a click plays: click() enables, queues the tick, and arms a
    250ms one-shot esp_timer that disables it after the tail drains
    (mutex-guarded against the timer task). Also halves the DMA footprint
    (4x180 frames — still holds a whole click, so writes never block) and
    moves the pre-rendered click to PSRAM.
    Escape hatch: "Button sounds" OFF + Restart now skips sound_begin()
    entirely, leaving the audio stack cold.
    Tab-bar b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
    [main.cpp]
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2026-07-19 brew: a paddle flip on a standby Micra wakes it, not a shot
    New optional standby provider on BrewController (device main wires it to
    'link Connected && power != On'). On a paddle ON edge in that state the
    controller still drives the line through — that's what actually powers the
    machine on — but skips the timer/tare/automation: no water moves, so there
    is no shot to track. The OFF edge is a no-op for the never-started timer
    (the last shot's held time survives) and the next flip with the machine
    awake runs as a normal shot. Disconnected/unknown state is unchanged, and
    the review-swallow still takes precedence.
    [brew_controller.h]
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2026-07-19 p4 wired paddle + audio, scale-settings label fix, review weight freeze fix, paddle glitch filter
    - P4 paddle (config-only): native GPIOs on the header corner — GND/52/51
    take one 3-pin screw terminal. GPIO52 drives a PC817 opto module's input;
    the module's output side runs VCC-floating so OUT/GND form an isolated
    dry contact (OUT -> Micra white, GND -> Micra black). Active-HIGH drive,
    opposite of the 4.3C's expander. GPIO51 reads the physical paddle switch
    to board GND (INPUT_PULLUP, low = closed) — the paddle touches only this
    board, never the Micra. Uses paddle.cpp's existing native-GPIO path.
    - P4 audio (config-only): the 4.3C's ES8311 click driver reused with the
    Wave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
    [board_config.h, brew_controller.h, main.cpp]
2026-07-21 unwired mode: weight-stream shot detector, wired-paddle toggle, shot-aligned review, stop-early hint
    No-paddle-harness brew UX (all boards; paddle boards opt in via the new
    Settings > Micra > Settings 'Wired paddle' switch, NVS wiredpad):
    - core::ShotDetector classifies the scale's weight stream (candidate ->
    confirm-after-sustain -> flow-cease end, step/blackout/runaway guards);
    BrewController drives the existing phases from it with a retroactive
    timer start, review gates (>=8s, >=5g), no auto-stop/overshoot learning.
    - Always-on UI sample ring while unwired; the live graph stays untouched
    mid-shot and review entry does a one-shot, shot-aligned repaint from the
    ring (lead-in + se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
    [brew_controller.h, main.cpp, shot_detector.h]
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
